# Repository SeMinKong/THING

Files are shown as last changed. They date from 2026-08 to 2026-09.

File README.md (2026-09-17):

<p align="center">
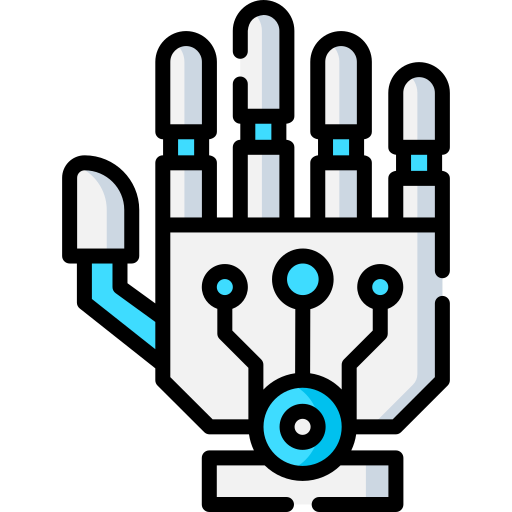
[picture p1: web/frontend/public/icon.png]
THING 로봇 손 로고
  
</p>

<h1 align="center">THING</h1>

<p align="center">
  <strong>손동작 인식부터 안전한 7축 구동과 실험 데이터 기록까지 연결한 텐던 로봇 핸드</strong>
</p>

THING은 사용자의 손동작을 실시간으로 인식해 7축 텐던 구동 로봇 손으로 재현하는
ROS 2 기반 Human-Mimetic Robot Hand입니다. MediaPipe가 검출한 21개 손 landmark를
네 손가락의 굽힘과 엄지의 굽힘·대립·벌림으로 구성된 7축 명령으로 변환합니다.

Jetson Orin Nano는 비전 인식과 동작 기록을, Raspberry Pi 5는 명령 중재·안전 검증과
DYNAMIXEL 제어를 담당합니다. React 관제 웹과 EC2 데이터 포털을 연결해 실시간 제어부터
실험 데이터 저장·조회까지 하나의 흐름으로 구현했습니다.

> **현재 구현 상태**
>
> 비전 인식, 명령 중재, 안전 검증, 7축 모터 구동, Web Bridge, 데이터 기록·업로드
> 경로를 통합했으며 실제 텐던 로봇 손으로 손동작 모방과 물체 파지 시연을 완료했습니다.

## 시연

### 최종 통합 시연

사용자의 손동작 인식과 7축 텐던 로봇 손의 실시간 모방 제어를 보여주는 최종 시연입니다.

https://github.com/user-attachments/assets/3f23d3e1-5532-4831-a1eb-fe4c024d04cb

> [원본 최종 시연 영상 열기](media/videos/모방시연.mp4)

### 동작 하이라이트

아래 미리보기는 모방·파지·독립 관절 동작 9개를 짧게 이어 보여줍니다.

<p align="center">
  실시간 손동작 모방, 여러 손동작 모방, 지연 개선 웨이브, 캔 파지, 유연 물체 파지, 손목보호대 파지, 엄지 3축, 손가락 웨이브, 카운트다운 시퀀스 하이라이트
</p>

<p align="center">
  <sub>각 동작의 전체 영상은 아래 목록에서 확인할 수 있습니다.</sub>
</p>

### 개별 시연 영상

<details>
<summary><strong>전체 원본 영상 펼쳐보기</strong></summary>

#### 통합·모방

- [최종 손동작 모방 시연](media/videos/모방시연.mp4)
- [7축 구동 시연](media/videos/최종시연.mp4)
- [여러 손동작 모방](media/videos/모방여러동작.mp4)
- [지연 개선 후 웨이브 모방](media/videos/모방웨이브지연개선.mp4)

#### 파지·시퀀스

- [캔 파지 모방](media/videos/모방캔파지.mp4)
- [유연한 물체 파지](media/videos/파지말랑이.mp4)
- [손목보호대 파지](media/videos/파지손목보호.mp4)
- [엄지 3축 동작](media/videos/엄지축.mp4)
- [손가락 웨이브](media/videos/파도타기.mp4)
- [카운트다운 시퀀스](media/videos/카운트다운.mp4)

</details>

원본 MP4 영상은 Git LFS로 관리합니다.

## 핵심 구현

| 영역 | 구현 내용 |
| --- | --- |
| 기구·전자 | 3D 프린팅 텐던 로봇 손, CAD·STL·URDF, 7축 DYNAMIXEL 배선과 안전 전원 자료 |
| 비전 | USB 카메라 프레임, MediaPipe Hands 기반 21개 landmark 검출, 정규화된 7축 `HandCommand` 생성 |
| 제어·안전 | MIMIC·MANUAL·TELEOP 명령 중재, Command Guard, GPIO E-Stop, 안전 상태 관리, XL330-M288-T 7축 구동 |
| 관제 UI | WebSocket·MJPEG 기반 실시간 상태 확인, 제어권 관리, 모방·수동 조작, 기록 판정 UI |
| 기록·데이터 | rosbag2 기록, metadata·Landmark JSON과 HandCommand·MotorStatus CSV exporter, SHA-256 검증, HTTPS uploader, EC2 세션 포털 |
| 운용 | ROS 2 장치별 launch, Jetson 비전·웹 실행 스크립트, Raspberry Pi 시연 자동화 스크립트 |

## 시스템 구성

```text
사용자 손
  → Camera / MediaPipe / 7축 목표 생성                (Jetson Orin Nano)
  → command_manager / command_guard / safety_manager (Raspberry Pi 5)
  → DYNAMIXEL XL330-M288-T × 7
  → 텐던 로봇 손

카메라·로봇 상태
  → Web Bridge (WebSocket + MJPEG)
  → React 관제·제어 웹                               (Laptop)

동작 데이터
  → rosbag2 → exporter → uploader                    (Jetson Orin Nano)
  → Django API / SQLite / 파일 저장                  (AWS EC2)
```

웹은 모터를 직접 제어하지 않습니다. 모든 일반 명령은 Raspberry Pi의 명령 중재와
안전 검증을 통과하며, 네트워크가 복구돼도 사용자의 명시적인 입력 전에는 자동으로
움직이지 않도록 구성했습니다.

## 직접 구현한 부분

- Codex의 Blender 스킬을 활용해 인체 손의 관절 구조를 모방한 모델을 설계하고, 3D 프린팅으로 제작했습니다.
- DYNAMIXEL 모터 7개의 제어값을 조정하고, 동기 구동과 키보드 기반 조작 기능을 구현했습니다.
- U2D2 기반 모터 통신 모듈을 구성하고, 제어 노드에서 전달한 데이터를 모터 명령으로 변환하는 ROS 브릿지를 구현했습니다.

## 트러블슈팅

- **모터 제어 범위 조정**: DYNAMIXEL SDK의 전류 제한, 토크 설정, 회전 범위, 제어 모드별 동작을 확인했습니다. 각 파라미터가 구동에 미치는 영향을 비교하며 로봇손의 기구 조건에 맞게 제어값을 조정했습니다.
- **텐던 구동과 복귀 구조**: 손가락을 굽히는 동작과 원위치로 복귀하는 동작을 함께 고려해야 했습니다. 관절의 힘 작용점을 계산하고 텐던 배치를 검토해, 장력을 이용하는 복귀 방식으로 구조를 변경했습니다.
- **ROS 통신 주기 개선**: 제어 명령의 전달 주기를 개선하기 위해 ROS 통신 설정을 조정하고 Cyclone DDS를 활용했습니다. 모터 구동과 데이터 전달을 함께 점검하며 실시간 제어를 위한 통신 환경을 구성했습니다.

## 회고

Physical AI를 위한 시뮬레이션 학습까지 진행하지는 못했지만, 로봇의 기구와 모터 제어를 연결하는 기초를 익혔습니다. 제작 과정에서 통신 오류와 하드웨어 한계를 경험하며 소프트웨어만으로 해결하기 어려운 조건들을 이해했습니다. 이를 바탕으로 기구·통신 구조를 개선하고, 이후 시뮬레이션 학습과 실제 제어를 연결할 프로젝트를 구상하고 있습니다.

## 구동부 구현과 설계 판단

저는 **Blender 모델링·3D 프린팅, U2D2 통신·7개 모터 동기 구동·키보드 제어, ROS 브릿지와 Cyclone DDS 통신 설정, 고정부·스풀·텐던 통합**을 담당했습니다. 손동작 인식, 명령 중재·guard·안전 상태, 관제 UI·기록 등은 팀원이 구현했습니다. 아래 표에는 제가 작성한 모터 점검 코드의 세부 처리를 정리했습니다.

| 확인한 문제 | 구현한 처리 | 확인 범위 |
| --- | --- | --- |
| 토크를 켤 때 이전 목표로 움직일 수 있음 | 이동 함수에서 현재 위치를 Goal Position에 먼저 기록 → Torque ON → 새 목표 적용 | 모터 점검 코드의 실행 순서 |
| 다회전 위치에서 원위치 복귀 경로가 길어짐 | 현재 위치에 가장 가까운 `2048 + 4096 × k` 선택 | 중앙각 복귀이며 손가락 끝점 보정과 구분 |
| 같은 엔코더 명령도 기구 상태에 따라 굽힘량이 달라짐 | 모터별 점검과 아크릴 고정부·스풀·텐던 조립, 권취·배선 경로 기록 | 최대 가동 범위 간섭·재조립 반복성은 추가 검증 필요 |

관절각·필터·모터 보정식, 토크 인가 순서와 실제 검증 범위는
[구동·기구 통합 기술 노트](docs/engineering-notes.md)에 정리했습니다.

## 기술 스택

| 구분 | 기술 |
| --- | --- |
| Robot·Edge | ROS 2 Humble, Jetson Orin Nano, Raspberry Pi 5 |
| Vision | MediaPipe Hands, OpenCV |
| Control | Python, C++, DYNAMIXEL XL330-M288-T, U2D2 |
| Web | React, Vite, WebSocket, MJPEG |
| Data | rosbag2, Django, SQLite, JSON·CSV, AWS EC2 |
| Fabrication | Blender, 3D Printing, Tendon-driven Mechanism |

## 빠르게 확인하기

### 저장소 받기

Git LFS가 필요합니다.

```bash
git lfs install
git clone https://github.com/SeMinKong/THING.git
cd THING
git lfs pull
```

### 로봇 없이 관제 UI 실행

```bash
cd web/frontend
npm ci
npm run mock
```

다른 터미널에서 다음 명령을 실행합니다.

```bash
cd web/frontend
npm run dev
```

### ROS 2 패키지 빌드

Ubuntu 22.04와 ROS 2 Humble 환경을 기준으로 합니다.

```bash
source /opt/ros/humble/setup.bash
cd thing_ws
rosdep install --from-paths src --ignore-src -r -y
colcon build --symlink-install
source install/setup.bash
colcon test
colcon test-result --verbose
```

실물 장비를 구동하기 전에는 장치별 설정과 안전 문서를 먼저 확인하세요.

## 저장소 구성

| 경로 | 내용 |
| --- | --- |
| [`mechanical/`](mechanical/) | CAD, STL, 도면과 조립 자료 |
| [`electronics/`](electronics/) | BOM, 회로, 배선과 안전 전원 자료 |
| [`thing_ws/`](thing_ws/) | ROS 2 인터페이스·비전·제어·하드웨어·로거·Web Bridge·bringup |
| [`web/frontend/`](web/frontend/) | 내부망 React 관제·제어 UI |
| [`scripts/`](scripts/) | Jetson 비전·Web Bridge 실행 스크립트 |
| [`exec/`](exec/) | Raspberry Pi 시연 실행·종료 스크립트 |
| [`EC2/thing_database_web/`](EC2/thing_database_web/) | 실험 데이터 포털 프런트엔드·백엔드 |
| [`tests/`](tests/) | 자동화 테스트와 실물 시험 절차 |
| [`docs/`](docs/) | 요구사항, 아키텍처, 인터페이스, 환경 설정과 개발 기록 |
| [`media/`](media/) | 프로젝트 이미지와 시연 영상 |

## 주요 문서

- [구동·기구 통합 기술 노트](docs/engineering-notes.md)
- [시스템 아키텍처](docs/architecture.md)
- [ROS 2·Web·EC2 인터페이스](docs/interfaces.md)
- [요구사항 명세서 V7.1](docs/requirements/요구사항%20명세서%20V7.1.md)
- [포팅 매뉴얼](exec/포팅_매뉴얼.md)
- [Safety Manager](docs/safety_manager.md)
- [Ubuntu 개발 환경](docs/setup/ubuntu.md)
- [DYNAMIXEL 설정](docs/setup/dynamixel.md)
- [내부 관제 웹](web/README.md)
- [Web Bridge](thing_ws/src/thing_web_bridge/README.md)
- [Logger·Landmark JSON 계약](thing_ws/src/thing_logger/README.md)
- [기구 자료](mechanical/README.md)
- [전자·배선 자료](electronics/README.md)
- [시험 절차](tests/README.md)
- [EC2 데이터 포털](EC2/README.md)

## Contributors

<p align="center"><strong>SSAFY 광주 1반 C103</strong></p>

<table align="center">
  <tr>
    <td align="center" width="160">
      <a href="https://github.com/binedwin">
        이정빈 GitHub 프로필<br>
        <strong>이정빈</strong>
      </a><br>
      <sub>팀장</sub>
    </td>
    <td align="center" width="160">
      <a href="https://github.com/s0415j">
        신수진 GitHub 프로필<br>
        <strong>신수진</strong>
      </a><br>
      <sub>팀원</sub>
    </td>
    <td align="center" width="160">
      <a href="https://github.com/akdlxm39">
        백지웅 GitHub 프로필<br>
        <strong>백지웅</strong>
      </a><br>
      <sub>팀원</sub>
    </td>
  </tr>
  <tr>
    <td align="center" width="160">
      <a href="https://github.com/yjmini">
        윤정민 GitHub 프로필<br>
        <strong>윤정민</strong>
      </a><br>
      <sub>팀원</sub>
    </td>
    <td align="center" width="160">
      <a href="https://github.com/lab0-hibears">
        김기현 GitHub 프로필<br>
        <strong>김기현</strong>
      </a><br>
      <sub>팀원</sub>
    </td>
    <td align="center" width="160">
      <a href="https://github.com/SeMinKong">
        공세민 GitHub 프로필<br>
        <strong>공세민</strong>
      </a><br>
      <sub>팀원</sub>
    </td>
  </tr>
</table>

## 안전

실제 모터에 토크를 인가하기 전에 모터 ID, 이동 범위, 전류 제한, 텐던 장력과
비상 정지·전원 차단 수단을 확인해야 합니다.

- [DYNAMIXEL 도구와 기본 점검](tools/dynamixel/README.md)
- [모터 제어 안전 지침](docs/motor-control/dynamixel/safety.md)
- [Raspberry Pi 현장 제어 안내](tools/dynamixel/rpi/README.md)

## 라이선스

이 프로젝트는 [Apache License 2.0](LICENSE)으로 배포됩니다.

## 원본 프로젝트 README

이 저장소는 SSAFY 팀 GitLab 프로젝트 `main`의 최종 스냅샷을 포트폴리오 형태로
정리한 버전입니다. 팀 개발 저장소에서 사용한 기술·협업 중심 README는
[README_LEGACY.md](README_LEGACY.md)에 보존했습니다.

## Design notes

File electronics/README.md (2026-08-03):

# Electronics

이 디렉터리는 `schematics/`의 회로도, `wiring/`의 실제 배선 자료와 `bom/`의 부품 목록을 관리합니다.

서보 전원, 마이크로컨트롤러, 배선, 센서와 안전장치를 관리합니다.

현재 MVP는 Raspberry Pi와 U2D2가 XL-330-288T 7개를 직접 제어하며 별도
마이크로컨트롤러를 사용하지 않습니다. 모터 1개는 예비입니다.

- `schematics/`: 회로도
- `wiring/`: 실제 배선도와 사진
- `bom/`: 부품 목록과 구매 상태

배선 문서에는 motor ID, U2D2 포트, 전원 분배, 퓨즈와 비상정지의 물리 전원
차단 경로를 반드시 표시합니다.

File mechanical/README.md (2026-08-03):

# Mechanical

이 디렉터리는 `cad/`의 설계 원본, `stl/`의 출력 파일과 `drawings/`의 치수·조립 도면을 관리합니다.

손가락 링크, 관절, 엄지 대립축, tendon 경로, spool 및 서보 마운트를 관리합니다.

- `cad/`: 수정 가능한 CAD 원본
- `stl/`: 3D 프린팅용 출력 파일
- `drawings/`: 치수 도면과 조립도

CAD 변경 MR에는 출력 방향, 소재, 조립 방법과 동작 시험 결과를 함께 기록합니다.

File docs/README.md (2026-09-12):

# Docs

이 디렉터리는 프로젝트 계획, 시스템 아키텍처, 분야 간 인터페이스와 일간·주간 진행 기록을 관리합니다.

- `requirements/`: 요구사항 명세서 버전 이력 관리 (`V6.3`이 현재 최종 기준)
- `setup/`: Ubuntu, Jetson, Raspberry Pi, 네트워크와 DYNAMIXEL 설정
- `daily-reports/`: 팀원별 일일 진행 상황과 장애 요소 기록
- `weekly-reports/`: 주간 목표, 결과와 다음 주 우선순위 기록

- [구동·기구 통합 기술 노트](engineering-notes.md): 개인 기여, 관절각·필터·보정식, 운용 주기와 검증 범위

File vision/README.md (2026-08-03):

# Vision experiments

이 디렉터리는 사용자 캘리브레이션 자료와 ROS 2에 넣기 전의 제한된 비전 실험을
관리합니다. 실제 실행 노드와 공용 알고리즘은
`thing_ws/src/thing_vision`에서 구현합니다.

- `calibration/`: 사용자별 편 손·주먹 기준과 샘플
- `experiments/`: 필요할 때 생성하는 일회성 MediaPipe·기하 계산 실험
- `requirements.txt`: ROS 비전 노드와 실험에서 공통으로 사용하는 Python 의존성

프로덕션 코드가 이 디렉터리와 `thing_vision`에 중복되지 않도록 합니다.

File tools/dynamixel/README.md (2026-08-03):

# DYNAMIXEL XL330 PC 제어 도구

XL330-M288-T 7축의 연결 상태를 확인하고, 안전한 보정·동작 계획을 수행하는 독립 실행 도구다. ROS 2 `thing_hardware` 통합 전의 PC·Raspberry Pi 하드웨어 점검에 사용하며, 운영 제어 경로를 대체하지 않는다.

## 설치

```bash
python3 -m venv dxl-env
source dxl-env/bin/activate
python -m pip install -r tools/dynamixel/requirements.txt
cp tools/dynamixel/hand_motion_config.example.json \
  tools/dynamixel/hand_motion_config.json
```

실제 장치별 포트, ID, 관절 역할, 개폐 위치값은 로컬 설정 파일에만 기록한다. 이 파일과 CSV 텔레메트리는 Git에서 제외된다.

## 기본 점검

```bash
python tools/dynamixel/scan_7_motors.py
python tools/dynamixel/hand_motion_7_motors.py plan
python tools/dynamixel/hand_motion_7_motors.py show
python -m unittest tests/dynamixel/test_hand_motion_offline.py -v
```

실제 토크 인가 전에는 모든 축의 역할과 이동 범위를 확인하고, 비상 정지와 전원 차단 수단을 준비한다.

## 관련 문서

- [실제 손 동작 코드 사용 순서](../../docs/motor-control/dynamixel/hand-motion.md)
- [배포 절차](../../docs/motor-control/dynamixel/deployment.md)
- [안전 지침](../../docs/motor-control/dynamixel/safety.md)
- [이식성 및 장치 설정](../../docs/motor-control/dynamixel/portability.md)
- [프로젝트 상태](../../docs/motor-control/dynamixel/project-status.md)

## Raspberry Pi 현장 제어 스크립트

`rpi/`에는 Raspberry Pi의 `~/thing_pjt/motor`에서 실제 7축 XL330·3개 U2D2 연결에 사용한
점검·제어 스크립트를 보관한다. 통합 손 동작 제어기와는 별도의 현장 점검 도구이며, 다음 작업을
포함한다.

- 7개 모터 통신·상태 조회와 단일 모터 제어
- 개별/전체 Torque OFF가 가능한 키보드 제어
- 모든 축의 2048 기준 원위치 복귀 및 출력 제한값 설정

`rpi/motor_config.json`에는 해당 장비의 `/dev/serial/by-id/` U2D2 경로가 들어 있다. 다른
제어기에서 사용하기 전에는 경로와 모터 ID를 확인하고 수정해야 한다. 상세 사용법은
[`rpi/README.md`](rpi/README.md)를 따른다.

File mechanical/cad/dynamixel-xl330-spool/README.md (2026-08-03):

# XL330 / HNX330-N101용 Ø12 저상형 2피스 스풀

이 설계는 손가락 굽힘용 2 mm 텐던을 부드럽게 제어하기 위한 **Ø12 mm 감김 드럼**과, HNX330-N101 호른에 고정되는 **분리형 베이스**로 구성됩니다.

호른 체결 나사가 작은 드럼의 감김면을 관통하지 않도록 베이스와 드럼을 분리했습니다. 장식용 줄 형상과 나선 홈은 없습니다.

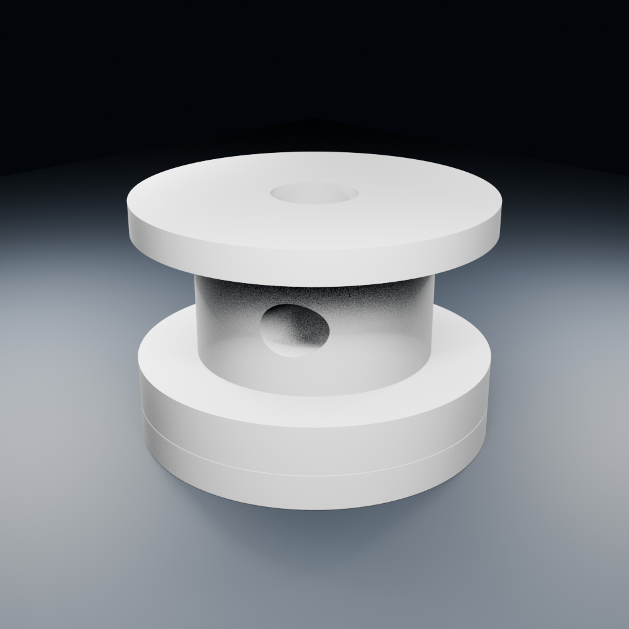
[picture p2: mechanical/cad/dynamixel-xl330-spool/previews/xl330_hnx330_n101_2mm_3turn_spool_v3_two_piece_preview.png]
조립 미리보기


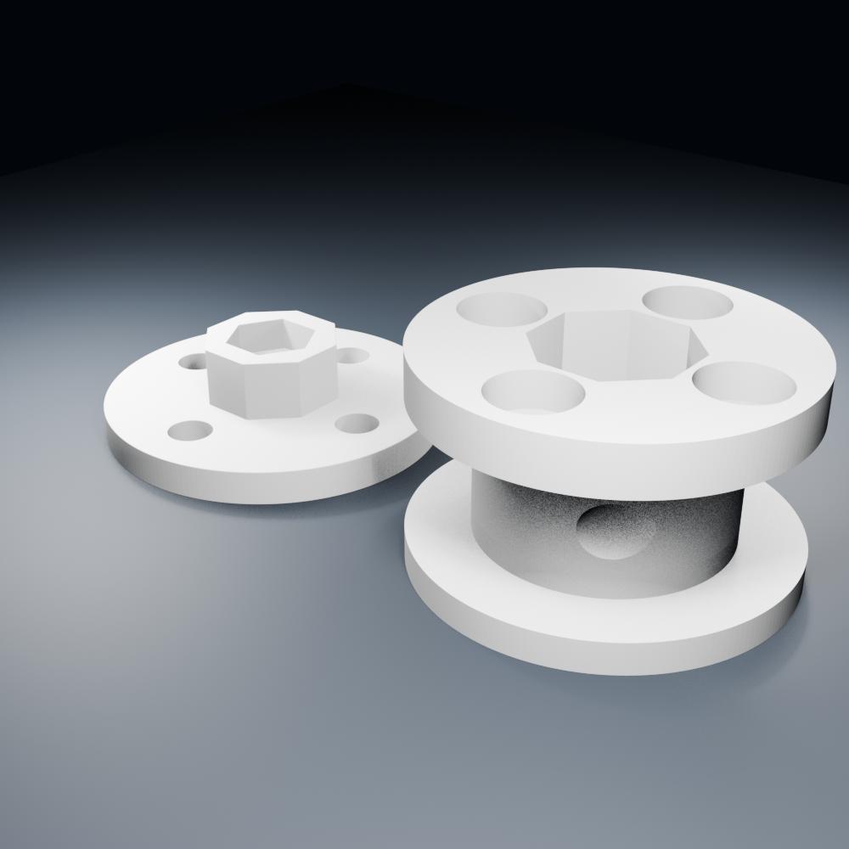
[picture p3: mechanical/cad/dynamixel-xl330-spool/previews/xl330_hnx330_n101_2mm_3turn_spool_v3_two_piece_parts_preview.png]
부품 및 출력 방향 미리보기


## 구성 파일

- `print/..._mount_base.stl`: 호른에 고정하는 베이스
- `print/..._drum.stl`: 2 mm 줄이 감기는 교체형 드럼
- `print/..._7set_bambu_plate.3mf`: 베이스 7개와 드럼 7개가 배치된 Bambu Studio 생산 플레이트
- `source/..._assembly.blend`: 두 부품이 결합된 Blender 원본
- `scripts/create_xl330_two_piece_spool.py`: 파라메트릭 Blender 생성 스크립트
- `scripts/validate_xl330_two_piece_spool.py`: 커밋된 STL 검증 스크립트

모델을 다시 생성하면 결과는 Git에서 제외된 `generated/`에 저장됩니다.

```bash
blender --background --python scripts/create_xl330_two_piece_spool.py
blender --background --python scripts/validate_xl330_two_piece_spool.py
```

## 주요 치수

### 드럼

| 항목 | 치수 |
|---|---:|
| 감김 코어 | Ø12.00 mm |
| 플랜지 외경 | Ø18.00 mm |
| 감김 유효 폭 | 6.50 mm |
| 줄 용량 | Ø2.00 mm 줄 1가닥 × 나란히 3회 |
| 하부 플랜지 | 2.40 mm |
| 상부 플랜지 | 1.60 mm |
| 드럼 전체 높이 | 10.50 mm |
| 팔각 허브 보어 | AF 7.25 mm × 깊이 3.60 mm |
| 중앙 체결홀 | Ø2.30 mm |
| 중앙 나사머리 자리 | Ø4.30 mm × 깊이 1.50 mm |
| 줄 고정용 가로 구멍 | Ø2.60 mm |

### 호른 베이스

| 항목 | 치수 |
|---|---:|
| 베이스 원판 | Ø18.00 × 1.80 mm |
| 호른 체결홀 | 4 × Ø2.30 mm |
| 체결홀 피치원 | PCD Ø12.00 mm |
| 팔각 토크 허브 | AF 6.80 × 높이 3.20 mm |
| 드럼과 팔각 끼움 여유 | 직경 방향 0.45 mm |
| 중앙 M2 너트 포켓 | AF 4.25 × 깊이 1.80 mm |
| 호른 중앙 나사 여유부 | Ø6.00 × 깊이 0.50 mm |
| 결합 상태 전체 높이 | 호른 면에서 12.30 mm |

모터 위치 범위 `100~3995 raw`를 전부 사용하면, 2 mm 줄 중심 기준 약 **41.824 mm**를 당깁니다. 이 값은 기하학적 최대 환산값이며 실제 손에서는 사용하지 않습니다. 텐던 연결 후 축별 안전 끝점을 작은 조그로 따로 보정해야 합니다.

## 필요한 체결 부품

- 호른 체결: **PHS M2×4 4개**
  - HNX330-N101에 포함된 나사를 사용할 수 있습니다.
- 드럼 체결: **M2×8 나사 1개**
  - 냄비머리 또는 버튼머리
  - 실제 나사머리 외경은 4.1 mm 이하 권장
- 드럼 체결용 **표준 M2 육각너트 1개**
  - 공칭 AF 4.0 mm, 두께 약 1.6 mm

## 권장 출력 설정

- 재료: PETG 또는 Nylon 권장
- 노즐: 0.4 mm
- 레이어: 0.16~0.20 mm
- 벽: 5겹 이상
- 상·하부: 6겹 이상
- 인필: 100% 권장
- 배율: 100%, 단위 mm

제공된 3MF에는 베이스와 드럼이 각각 7개 배치되어 있습니다. Bambu Studio 2.7.1.62에서 작성했지만, 출력 전에 사용 중인 프린터·노즐·필라멘트 프로파일과 서포트 설정을 반드시 다시 확인합니다.

출력 방향:

- 베이스: 평평한 호른 접촉면을 베드에 놓고 팔각 허브가 위를 향하게 출력
- 드럼: 중앙 M2 나사머리 자리가 있는 면을 베드에 놓고, 팔각 보어와 나사머리 포켓이 위를 향하게 출력

드럼의 마지막 플랜지 밑면이 처지는 프린터에서는 감김 공간에만 `build plate only` 서포트를 적용합니다.

출력 후 다음 부분을 손으로 정리합니다.

- M2 체결홀: Ø2.3 드릴
- 호른 나사머리 포켓: 실제 나사머리가 완전히 들어가도록 Ø4.1 드릴 또는 리머
- 줄 고정홀: Ø2.6 드릴
- 팔각 끼움이 너무 빡빡하면 베이스 허브의 평평한 면만 조금씩 사포질

## 조립 순서

1. 모터 전원을 끄고 토크가 해제됐는지 확인합니다.
2. 베이스의 구멍 4개를 HNX330-N101의 M2 나사홀에 맞춥니다.
3. PHS M2×4 나사 4개를 모두 가볍게 건 뒤 대각선 순서로 조금씩 조입니다.
4. 표준 M2 육각너트를 베이스 팔각 허브 중앙의 육각 포켓에 넣습니다.
5. 드럼 밑면의 나사머리 포켓 4개를 베이스 나사머리에 맞추면서 팔각 허브에 끼웁니다.
6. 드럼 위에서 M2×8 나사를 넣어 중앙 너트에 가볍게 조입니다.
7. 2 mm 줄을 드럼의 Ø2.6 가로 구멍으로 통과시킨 뒤 나란히 최대 3회 감습니다.

중앙 M2 나사는 드럼이 빠지지 않게 누르는 역할이고, 회전 토크는 팔각 허브가 전달합니다. 플라스틱을 압착할 정도로 중앙 나사를 세게 조이지 마십시오.

## 검증 결과

### 베이스 STL

- 외형: 18.0000 × 18.0000 × 5.0000 mm
- 연결된 메쉬: 1개
- 비매니폴드 에지: 0개
- 느슨한 정점: 0개

### 드럼 STL

- 외형: 18.0000 × 18.0000 × 10.5000 mm
- 연결된 메쉬: 1개
- 비매니폴드 에지: 0개
- 느슨한 정점: 0개

### 조립 여유

- 팔각 AF 여유: 0.450 mm
- M2 너트 AF 여유: 0.250 mm
- 호른 나사머리 포켓 위 잔여 두께: 0.600 mm
- 줄 고정홀과 중앙 M2 홀 사이 최소 여유: 0.950 mm

## 적용 대상

이 모델은 ROBOTIS 공식 도면의 `외경 Ø16`, `4-M2×0.4 TAP THRU`, `PCD Ø12` 체결 패턴을 가진 **HNX330-N101** 기준입니다.

- [ROBOTIS HNX330-N101 제품 정보](https://www.robotis.us/hnx330-n101-set/)
- [ROBOTIS 공식 도면 다운로드 센터](https://en.robotis.com/service/downloadpage.php?ca_id=7020)

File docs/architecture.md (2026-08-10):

# 시스템 아키텍처

## 장치별 책임

| 장치 | 책임 |
| --- | --- |
| Jetson Orin Nano | RGB 카메라, MediaPipe, 7논리축 목표, overlay/MJPEG, Web Bridge, Logger·exporter·uploader |
| Raspberry Pi 5 | 제어권 중재, 명령 검증, 안전, DYNAMIXEL |
| Laptop | 내부망 관제·제어 웹, TELEOP와 개발 |
| AWS EC2 | 공개 데이터 포털, SQLite와 세 파일 영속 저장 |

## 제어 데이터 흐름

```text
사용자 손
  → camera_node
  → mediapipe_node
  → HandLandmarks
  → hand_target_node
  → /thing/command/mimic
                         ┐
웹 Gesture/Sequence ─────┼→ command_manager → /thing/command/selected
로컬 TELEOP ─────────────┘
  → command_guard
  → /thing/command
  → dynamixel_node
  → XL-330-288T × 7
  → MotorStatus / diagnostics
```

웹은 모터에 직접 명령하지 않습니다. 모든 일반 명령은 `command_manager`와
`command_guard`를 통과해야 합니다.

## 관제와 기록 흐름

```text
camera overlay → MJPEG ───────────────────────┐
ControlState / SafetyState / RecordingState ──┼→ thing_web_bridge
HandCommand / MotorStatus ────────────────────┘       │
                                                      ├→ WebSocket → Laptop 내부 제어 웹
                                                      └→ MJPEG ────→ Laptop 내부 제어 웹

MIMIC recording request
  → thing_logger
  → rosbag2(HandLandmarks, HandCommand, MotorStatus, state topics)
  → 사용자 SUCCESS/FAILURE 판정
  → Logger 측 exporter
  → metadata JSON + HandCommand CSV + MotorStatus CSV
  → 격리 uploader 데몬(thing_logger.uploader, 별도 프로세스)
  → Bearer Token HTTPS
  → EC2 Django STAGING 검증
  → EC2 SQLite READY + EC2_DATA_DIR
  → 공개 GET 조회·세 파일 다운로드
```

카메라와 Vision은 녹화 여부와 무관하게 계속 동작합니다. 카메라 영상은 MJPEG
관제에만 사용하고 파일 또는 rosbag2에 저장하지 않습니다.

로봇의 로컬 시계열 원본은 rosbag2입니다. 별도 애플리케이션 SQLite,
`session_state.json`과 영구 upload spool은 만들지 않습니다. 업로드 실패 세션은
보존된 rosbag2와 SUCCESS/FAILURE를 입력받는 수동 재업로드 절차로 처리합니다.

## 제어 모드와 안전

- `DISABLED`: 일반 명령 차단
- `MIMIC`: MediaPipe 명령 사용
- `MANUAL`: 웹 Gesture·Sequence 사용
- `TELEOP`: 로컬 키보드 개별축 제어

안전 상태는 `INIT → READY → RUN → HOLD → SAFE/FAULT`로 관리하며 비상정지는
별도 `ESTOP` 상태입니다. Raspberry Pi의 제한과 비상정지는 웹·Jetson 장애와
독립적으로 동작해야 합니다.

`SAFE`, `FAULT`, `ESTOP` 복구는 `/thing/reset_safety`의 INIT 재검사를 거쳐
READY까지만 전환합니다. 이전 mode·owner·명령·queue·녹화는 자동 복원하지
않습니다.

## 네트워크 원칙

- 프로젝트 내부망에서만 제어합니다.
- 장치들은 같은 ROS Domain ID와 합의된 DDS 설정을 사용합니다.
- 명령 timestamp는 장치 간 시간 동기화를 전제로 합니다.
- 네트워크가 복구돼도 명시적인 재개 입력 전에는 자동으로 움직이지 않습니다.
- EC2에는 ROS 2 DDS와 로봇 제어 API를 노출하지 않습니다.
- EC2 포털은 HTTPS 공개 GET으로 READY 데이터만 조회하고, 업로드는 장치별
  Bearer Token을 사용하는 Jetson uploader만 수행합니다.

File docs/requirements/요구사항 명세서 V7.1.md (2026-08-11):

# 요구사항 명세서 V7.1(이제 수정은 여기서!!!!!)

업무 영역: 기획
업무 항목 현황: 대기
개별 진행률: 0%
진행률: 0%
최종 편집 일시: 2026년 8월 5일 오후 5:40

## 변경 이력

| 버전 | 변경 내용 |
| --- | --- |
| V5 | ROS 2 인터페이스, 내부망 관제·제어 웹 및 데이터 기록 명세 |
| V5.2 | V5의 누락 항목 보완 및 7논리축·7모터 구조 통일 |
| V6 | EC2 기반 외부 데이터 포털 추가, develop ROS 2 인터페이스 동결, 로봇의 별도 애플리케이션 DB 제거와 rosbag2 기반 EC2 직접 업로드, 안전 정책·2주 우선순위 및 Docker 배치 정합성 보정. Logger exporter·격리 uploader 분리, 수동 재업로드 CLI, content_digest 멱등성, Laptop 내부 제어 웹·두 웹 디렉터리와 WebSocket·EC2 GET JSON 계약 확정 |

## 1. 프로젝트 개요

### 1.1 프로젝트 배경 및 목적

본 프로젝트는 카메라로 사용자의 오른손 자세를 인식하고, 텐던 방식의 3D 프린팅 로봇 손이 해당 자세를 실시간으로 따라 움직이도록 구현하는 것을 목적으로 한다. 각 손가락의 여러 관절을 하나의 모터로 함께 구동하는 언더액추에이티드 구조를 적용해 가격·무게·제작 난도를 낮추고, 제한된 기간 안에 반복 가능한 파지 성능을 검증한다.

현재 MVP의 핵심 시연 범위는 다음과 같다.

- 편 손·주먹 및 엄지 굽힘·대립·벌림을 포함한 7논리축 실시간 모방
- 원통형 물체 파지와 엄지–검지 집기
    - ROS 2 기반 내부망 명령 전달과 Raspberry Pi의 독립 안전 제어
- MediaPipe landmark, HandCommand, MotorStatus 및 실험 결과의 로컬 rosbag2 기록
- 내부망 관제·제어 웹의 MIMIC·MANUAL 운용
- EC2 데이터 포털의 완료 세션 조회와 metadata JSON·HandCommand CSV·MotorStatus CSV, LandMark JSON 다운로드

EC2 데이터 포털은 저장된 데이터의 공개 읽기 전용 서비스이며 로봇 제어 경로를 제공하지 않는다. 장기적인 학습 데이터·모델 사업화는 현재 MVP 범위에 포함하지 않는다.

프로젝트 전체 계획은 3주이며, 이 문서를 동결하는 시점의 잔여 개발 기간은 2주다. Must 기능의 통합 시연을 우선하고 Should·Could 기능은 Must 검수에 영향을 주지 않는 범위에서만 진행한다.

---

### 1.2 MVP

1. **로봇 손 구동**
    - 제작 범위
        - 3D 모델링
        - 관절 연결
        - 텐던 연결
        - 모터 연결
    - 검증 동작
        - 손 펴기와 쥐기
        - 원통형 물체 파지
        - 엄지–검지 집기
        - 가벼운 물체 2종을 각각 10회 시험하여 7회 이상 파지
2. **실제 손동작 모방**
    - MediaPipe 기반 손 landmark 검출
    - 손가락 굽힘과 엄지 대립 및 벌림 정도 계산
    - 모터에 전달
    - 7논리축을 7개 물리 모터에 1:1로 연결한다
    - 손동작 모방을 `camera_node → mediapipe_node → hand_target_node`로 구체화
3. **ROS 2 패키지**
    - ROS 2 토픽·노드·서비스·액션 인터페이스 정의 및 구현
    - ROS 2를 통한 무선 명령 전달
    - ROS 2를 이용한 모터 동작
4. **완성형 웹 사용자 인터페이스**
    - 모방 모드에서 실시간 카메라 영상과 손 인식 결과 모니터링
    - 조작 모드에서 웹 버튼으로 로봇 손 제어
    - 모방 모드와 조작 모드는 별도 화면 또는 탭으로 구성
5. **EC2 기반 로봇 데이터 포털**
    - 기존 내부망 관제·제어 웹과 별도의 웹사이트로 구성한다.
    - 완료된 실험 세션 목록을 조회할 수 있다.
    - 세션별 HandCommand와 MotorStatus 데이터를 확인할 수 있다.
    - 세션 메타데이터 JSON과 HandCommand·MotorStatus CSV·LandMark JSON을 모두 다운로드할 수 있다.
    - 원본 rosbag2 업로드·다운로드는 2주 MVP에서 제외하고 Post-MVP Could로 분류한다.
    - EC2 웹에서는 로봇 제어, 녹화 시작·종료 및 모드 변경 기능을 제공하지 않는다.

#### MVP 제외 범위 - 향후 확장 기능

- 관절 각 선형 회귀 AI 모델 - Could
- VLA 기반 자율 조작
- Imitation Learning 모델 학습
- Isaac Sim 및 Isaac Lab 연동
- 손가락 관절별 독립 다축 제어
- 모든 관절의 실제 각도 측정
- 손가락 전체 촉각 센서
- 물체 종류 자동 인식
- 물체 위치 자동 탐색
- 클라우드 또는 외부 인터넷을 통한 로봇 원격 제어
- 산업용 수준의 방수·방진·내구성 확보
- 축–모터 결합·공유 구동은 MVP에서 사용하지 않는다

EC2 기반 데이터 조회 및 다운로드 기능은 MVP에 포함한다. 단, 외부 인터넷에서 로봇으로 명령을 전달하는 기능은 MVP 및 EC2 배포 범위에서 제외한다.

향후 학습 데이터 활용을 위해 MediaPipe landmark, 목표 명령, 모터 엔코더값 및 파지 성공 여부는 MVP에서도 저장한다.

---

### 1.3 제품 및 시스템 기능 요약

시스템은 손동작 인식, 명령 중재·검증, 모터·안전 제어, 실험 기록·업로드의 네 영역으로 구성한다. 상세 배치는 4장, ROS 2 계약은 6.3절, EC2 계약은 6.5절을 단일 기준으로 사용한다.

1. **내부망 관제·제어 웹**
    - 프로젝트 내부 네트워크에서 MIMIC·MANUAL 모드, MJPEG 영상, 손 검출, 7논리축 목표, 모터·안전·기록 상태를 제공한다.
    - 제어 요청은 Web Bridge와 검증된 ROS 2 인터페이스를 거치며 모터에 직접 접근하지 않는다.
    - 기록 시작·종료와 성공·실패 판정을 요청한다.
2. **EC2 데이터 포털**
    - 외부 인터넷에서 완료·판정된 단일 로봇 세션을 로그인 없이 조회한다.
    - metadata JSON, HandCommand CSV, MotorStatus CSV, LandMark JSON 정확히 네 파일을 표시·다운로드한다.
    - ControlState·SafetyState 변경 이력, 영상과 rosbag2는 MVP 공개 대상에서 제외한다.
    - 로봇 제어, 모드 변경, 기록 제어, Safety Reset 및 ROS 2 DDS 참여를 금지한다.

로봇에는 별도의 애플리케이션 SQLite, `session_state.json` 및 영구 upload spool을 두지 않는다. rosbag2가 로컬 원본이며, 정상 종료와 판정 완료 직후 `thing-logger`의 exporter가 정확히 네 파일을 임시 디렉터리에 생성·검증한다. 격리된 uploader는 rosbag2를 읽지 않고 완료된 네 파일만 받아 Bearer Token HTTPS로 EC2 Django 업로드 API에 즉시 전송한다. EC2 Django가 검증한 세션 정보는 EC2 SQLite에, 다운로드 파일은 `EC2_DATA_DIR`에 저장하며 이 둘이 공개 READY 데이터의 최종 기준이다. Laptop에서 실행하는 내부망 관제·제어 웹은 Web Bridge의 WebSocket과 Jetson MJPEG로 ROS 2 실시간 데이터를 받고, EC2 포털은 Django의 공개 GET API로 저장된 데이터만 조회한다.

MJPEG가 `/thing/image_raw`와 `/thing/landmarks`를 구독해 생성

#### 내부망 웹 기반 운용 흐름

- 카메라와 Vision Node는 기록 여부와 관계없이 계속 동작하며 원본 영상은 저장하지 않는다.
- MIMIC은 검출된 손으로 7논리축 명령을 생성하고 MANUAL은 사전 정의 자세를 실행한다.
- Raspberry Pi는 활성 mode·owner와 안전 상태에 맞는 입력 하나만 선택하고 유효성·범위·속도를 검증한다.
- 기록은 MIMIC에서만 허용하며 기록 중 모드 변경을 거부한다.

#### ROS 2 통합 실행 및 수동 시험

- 운영자는 장치별 실행 절차로 Laptop 내부 제어 웹, Jetson과 Raspberry Pi 스택을 시작한다.
- 필요 시 `teleop_keyboard`로 각 축을 시험한다.
- 편 손·주먹·파지·집기는 Must이며 가위바위보·카운트다운 Sequence는 Could다.

---

### 1.4 사용자 및 이해관계자

| 구분 | 역할 및 요구사항 |
| --- | --- |
| 조작 사용자 | 카메라 앞에서 손동작을 수행하거나 내부망 관제·제어 웹에서 명령을 선택해 로봇 손을 제어한다. |
| 기구 개발자 | 손가락, 텐던, 스풀, 스프링 및 모터 고정 구조를 설계하고 조정한다. |
| 소프트웨어 개발자 | MediaPipe, ROS 2, 모터 제어 및 데이터 저장 기능을 구현한다. |
| 웹 개발자 | 프론트엔드와 백엔드를 구현하고 사용자 화면을 설계한다. |
| 프로젝트 관리자 | 일정, 요구사항, 우선순위, 위험 요소 및 스프린트를 관리한다. |
| 평가자 및 관람자 | 손동작 모방, 물체 파지 동작을 확인한다. |
| 데이터 조회 사용자 | EC2 데이터 포털에 접속하여 세션별 로봇 데이터를 확인하고 다운로드한다. 로봇 제어 권한은 가지지 않는다. |
| 시스템 운영자 | EC2 서버, 데이터 업로드 상태, 저장 공간, 인증 정보 및 배포 상태를 관리한다. |

---

### 1.5 개발 환경

#### 1.5.1 하드웨어 환경

**현재 보유 장비**

- 3D 프린팅 로봇 손, 지름 2mm 철심과 텐던 소재
- U2D2 3개와 U2D2 Power Hub Board 3개
- DYNAMIXEL XL330-M288-T 8개: 활성 구동 7개, 예비 1개

**개발·통합 장비**

- Laptop, RGB 카메라, Jetson Orin Nano, Raspberry Pi 5
- 7개 모터의 순간 전류를 감당하는 별도 전원 공급 장치
- 스프링, 나일론선 및 물리적 E-Stop 주접점·NC 보조접점 회로

#### 1.5.2 소프트웨어 환경

- Jetson: JetPack 6.2·Ubuntu 22.04, Docker Engine. 비전·MJPEG·Web Bridge 이미지를 버전 관리된 `docker run` 스크립트로 실행하며 Docker Compose를 사용하지 않는다.
- Raspberry Pi: Ubuntu 24.04·Docker Engine. `docker compose up -d`를 유일한 표준 시작 방식으로 사용한다.
- Laptop: 내부망 제어 웹의 `web/*~~internal-control/~~*frontend` Vite+React를 native Node.js 환경에서 실행한다. Docker를 사용하지 않으며 브라우저는 Jetson Web Bridge WebSocket과 MJPEG에 내부망으로만 연결한다.
- EC2: Docker와 Compose를 사용하지 않는다. `EC2/frontend`의 React 정적 빌드를 Nginx가 제공하고 `EC2/backend`의 Django REST API·Gunicorn을 Python 가상환경과 systemd 서비스로 실행한다.
- 공통: ROS 2 Humble, C++·Python·JavaScript, OpenCV, MediaPipe, DYNAMIXEL SDK, rosbag2
- 내부망 웹: Laptop Vite+React, Jetson*~~(Django 삭제)*~~ ·Web Bridge WebSocket·MJPEG
- EC2 포털: Vite+React, Django REST API, Nginx, Gunicorn, HTTPS
- 로봇 로컬 저장(Jetson): `ROBOT_DATA_DIR=/var/lib/thing-robot-data` 아래 rosbag2 원본과 업로드 시점에만 생성하는 임시 네 파일. 별도 애플리케이션 SQLite·`session_state.json`·영구 spool은 사용하지 않음
- EC2 저장: SQLite `/var/lib/thing-data/db.sqlite3`와 `EC2_DATA_DIR` 파일 디렉터리
- 데이터 계약: 단일 로봇, UTC, `schema_version=1`, `data_version=1`, 공개 파일 정확히 네 개
- VCS/업무 관리: Git·GitLab, Jira, Notion

---

## 2. 주요 사용 시나리오

### UC-01-01. 실시간 손동작 모방(MIMIC 모드)

1. 사용자가 카메라 앞에 손을 위치시킨다.
2. 시스템이 손 landmark를 검출한다.
3. 시스템이 손가락별 굽힘값과 엄지 대립 및 벌림값을 계산한다.
4. 7논리축 목표값이 Raspberry Pi로 전달된다.
5. 로봇 손이 사용자의 손 자세를 따라 움직인다.
6. 카메라 프레임→landmark→7축→command manager 순서로 단계 수정

### UC-01-02. 웹 명령 기반 로봇 손 조작(MANUAL 모드)

1. 사용자가 내부망 관제·제어 웹에서 명령을 선택한다.
2. 7논리축 목표값이 Raspberry Pi로 전달된다.
3. 로봇 손이 전달된 목표값에 따라 움직인다.

### UC-02-01. 원통형 물체 파지(MIMIC 모드)

1. 원통형 물체를 로봇 손의 파지 영역에 배치한다.
2. 사용자가 손을 오므린다.
3. 로봇 손가락이 물체와 접촉한다.
4. 직렬 스프링이 추가 모터 이동을 흡수하며 물체를 누른다.
5. 로봇 손이 물체를 최소 3초 이상 유지한다.

### UC-02-02. 원통형 물체 파지(MANUAL 모드)

1. 사용자가 MANUAL 모드에서 원통형 물체 파지 명령을 선택한다.
2. 시스템이 사전에 정의된 7논리축 목표값을 생성한다.
3. Raspberry Pi가 명령의 유효성과 안전 상태를 검사한다.
4. 로봇 손가락이 원통형 물체를 감싸도록 움직인다.
5. 로봇 손이 물체를 최소 3초 이상 유지한다.

### UC-03. 엄지–검지 집기

1. 가벼운 소형 물체를 엄지와 검지의 집기 영역에 배치한다.
2. 사용자가 MIMIC 모드에서 집기 동작을 수행하거나 MANUAL 모드에서 집기 명령을 선택한다
3. 시스템이 엄지 굽힘·대립축과 검지 굽힘축의 목표값을 생성한다.
4. 엄지 끝과 검지 끝 또는 검지 측면이 물체에 접촉한다.
5. 로봇 손이 물체를 최소 3초 이상 유지한다.

> **사용 사례 번호 변경 기록:** 기존 UC-04(로컬 데이터 기록)는 기록부터 공개 조회까지의 단일 흐름을 만들기 위해 폐기했으며 이력 추적을 위해 번호를 재사용하지 않는다. 기존 UC-07(EC2 업로드)과 UC-08(EC2 조회·다운로드)은 각각 아래 UC-05의 B와 C로 통합했다.
> 

### UC-05. 실험 데이터 기록·직접 업로드·조회 및 다운로드

#### A. 로컬 기록

1. 사용자가 내부망 웹의 MIMIC 모드에서 기록 시작을 요청한다.
2. Logger가 0이 아닌 고유 `uint64` Session ID를 생성하고 rosbag2 기록을 시작한다. 활성 세션 상태는 실행 중 메모리와 RecordingState로만 관리한다.
3. Logger는 landmark, 최종 HandCommand, MotorStatus, ControlState, SafetyState와 기록 상태를 rosbag2에 저장하며 카메라 원본 영상은 저장하지 않는다.
4. 정상 종료 후 rosbag2를 닫고 실행 중 메모리에서 결과 판정을 기다린다. 사용자가 SUCCESS 또는 FAILURE를 판정하기 전에는 다음 정상 기록을 시작할 수 없다.
5. 안전 이벤트나 프로세스 종료로 중단된 rosbag2는 남기지 않는다.

#### B. EC2 직접 업로드

1. 판정 완료 직후 `thing-logger`의 exporter가 rosbag2를 읽어 metadata JSON, HandCommand CSV, MotorStatus CSV, LandMark JSON 를 세션별 임시 디렉터리에 생성한다.
2. exporter는 네 파일을 .part로 작성하고 schema·행 수·SHA-256을 검증한 뒤 최종 파일명으로 atomic rename한다. metadata에서 content_digest 필드만 제거한 canonical JSON byte와 세 데이터 파일의 고정 정보를 이용해 SHA-256 content_digest를 계산한다
3. exporter는 완료 디렉터리의 절대경로, 네 파일의 파일명·크기·행 수·SHA-256과 content_digest를 manifest로 구성하여 private Unix socket으로 uploader에 전달한다. uploader는 rosbag2에 접근하지 않으며, exporter는 네트워크 업로드와 EC2 응답 검증을 담당하지 않는다. uploader는 rosbag2에 접근하지 않는다.
4. uploader는 완료된 네 파일만 장치 Bearer Token과 HTTPS로 EC2 Django 업로드 API에 즉시 비동기 전송한다.
5. EC2는 STAGING에서 검증한 뒤 파일 디렉터리 이동과 SQLite 상태 전이로 READY만 공개한다.
6. 
- uploader는 handoff 요청을 수락하면 session_id, accepted, reason으로 구성된 ACK를 반환한다. ACK에는 content_digest를 포함하지 않는다.
- handoff 시도가 종료되면 exporter worker는 성공 여부와 관계없이 임시 canonical 네 파일을 정리한다. 완료된 원본 rosbag2는 삭제하지 않고 보존한다.
- MVP에서는 수동 재업로드 CLI, 영구 업로드 대기열, 자동 재시도 및 프로세스 재시작 후 실패 작업 복구를 제공하지 않는다.

> 여기서 “바로 업로드”는 기록 중 실시간 HTTP 전송이 아니라 **정상 종료와 판정 직후 시작하는 비동기 업로드**를 뜻한다.
> 

#### C. 공개 조회·다운로드

1. 외부 사용자는 로그인 없이 READY 세션 목록과 상세를 조회한다.
2. 기본 MVP는 Session ID·UTC 시각·결과와 7논리축·모터 데이터를 표 또는 기본 그래프로 확인한다.
3. 사용자는 metadata JSON, HandCommand CSV, MotorStatus CSV, LandMark JSON 정확히 네 파일을 다운로드한다.
4. EC2에서는 로봇 제어, 모드 변경, 기록 제어, Safety Reset과 rosbag2·상태 이력 공개를 제공하지 않는다.

표시 각도는 DYNAMIXEL encoder 기반 모터축 각도이며 실제 손가락 관절각이 아니다.

---

### UC-06. ROS 2 시스템 실행

1. 사용자가 Laptop의 내부 제어 웹 Vite 실행 명령, Jetson의 `docker run` 스크립트와 Raspberry Pi의 `docker compose up -d`를 실행한다.
2. Laptop은 `web/*~~internal-control/~~*frontend`의 React 화면을 제공하고, Jetson 컨테이너는 카메라·MediaPipe·MJPEG·Web Bridge**·Logger·exporter와 격리된 uploader**를, Raspberry Pi 컨테이너는 manager·guard·safety·DYNAMIXEL을 시작한다.
3. 모든 제어 노드는 이전 상태를 폐기하고 INIT에서 시작한다.
4. 사용자가 Laptop의 내부망 관제·제어 웹 또는 로컬 프로그램에서 제어 모드를 선택한다.
5. command manager가 현재 제어 모드와 제어권에 맞는 입력원 하나를 선택한다.
6. command guard가 선택된 명령의 timestamp, 범위, 속도 및 안전 상태를 검사한다.
7. 검증된 목표만 DYNAMIXEL 제어 노드에 전달한다.
8. 모터 상태, 제어 모드, 안전 상태 및 진단 정보를 ROS 2 토픽으로 발행하고 Jetson Web Bridge가 6.4절의 WebSocket snapshot으로 Laptop에 전달한다.
9. Jetson vision 실행 노드를 `camera_node`, `mediapipe_node`, `hand_target_node`, `mjpeg_streamer`, `web_bridge_node, logger`
    1. 격리 uploader는 launch 밖 별도 프로세스

제어 모드는 다음과 같이 구분한다.

- `DISABLED`: 일반 명령 비활성화
- `MIMIC`: MediaPipe 기반 실시간 손동작 모방
- `MANUAL`: 내부망 웹에서 Gesture 서비스와 Sequence 액션 실행
- `TELEOP`: 로컬 키보드 기반 개별축 조작

내부망 관제·제어 웹은 MIMIC과 MANUAL 모드 모두를 관제할 수 있다. 데이터 기록은 MIMIC 모드에서만 허용하며 기록 중에는 제어 모드를 변경할 수 없다.

---

## 3. 기능 요구사항

우선순위는 다음과 같이 구분한다.

- **Must:** 남은 2주 안에 통합·검수까지 반드시 완료할 기능
- **Should:** Must가 통과한 뒤 구현하며 단순화하거나 다음 스프린트로 이월할 수 있는 기능
- **Could:** 이번 2주 MVP 완료 조건에서 제외하고 시간이 남을 때만 진행할 기능

### 3.1 손 자세 인식

#### FR-01. 손 landmark 검출

**우선순위: Must**

시스템은 RGB 카메라에서 한 사용자의 오른손과 MediaPipe 21개 landmark를 검출해야 한다.

인수 조건:

- `HandLandmarks.detected`, `confidence`, `handedness`를 develop 인터페이스 그대로 발행한다.
- MIMIC 유효 기준은 `detected=true`, 오른손, `confidence>=0.70`이다.
- 손 미검출 또는 낮은 신뢰도가 150ms 연속되면 MIMIC HandCommand 발행을 중단하고 hand-loss latch를 설정한다.
- 명령 중단 뒤 FR-35의 300ms HOLD, 총 1000ms SAFE 정책이 동작해야 하며 미검출값을 새 정상 명령으로 대체하지 않아야 한다.
- 재검출은 위 유효 조건이 300ms 연속 유지되어야 인정한다. 재검출은 복구 조건 확인일 뿐 이전 명령이나 제어를 자동 재개하거나 즉시 latch를 해제하지 않는다.
- 이후 복구는 현재 SafetyState에 따라 FR-35만을 따른다. HOLD에서는 활성 mode·owner 아래 Guard 검증 activity가 최대 gap 100ms로 300ms 연속되면 RUN으로 자동복귀할 수 있다. 명시적 STOP을 선택한 경우 RESET→READY 뒤 mode·owner를 새로 획득한다. SAFE·FAULT·ESTOP에서는 원인 해소·안정 시간·`/thing/reset_safety`·INIT 재검사·READY 전환 뒤 mode·owner를 새로 획득한다.
- 모든 경로에서 활성화 이후 생성된 새로운 HandCommand만 실행하며 이전 command, Gesture, Sequence 및 recording을 자동 재개하지 않는다.
- 웹은 FR-27에 따라 미검출, latch, 현재 안전 상태와 필요한 복구 경로를 구분해 표시해야 한다.
- landmark overlay 품질 개선과 원시 좌표 상세 표시는 Should다.
- `camera_node`, `mediapipe_node`, `hand_target_node`
- 미검출 landmark 좌표는 유효값으로 사용하지 않음

#### FR-02. 손가락 굽힘값 계산

**우선순위: Must**

시스템은 검지, 중지, 약지, 소지 및 엄지의 landmark를 사용하여 각 손가락의 굽힘 정도를 계산해야 한다.

인수 조건:

- 각 손가락의 굽힘값을 `0.0~1.0` 범위로 표현해야 한다.
- `0.0`은 편 상태, `1.0`은 최대 굽힘 상태로 정의한다.
- 손 크기와 카메라 거리에 따른 영향을 최소화해야 한다.
- 비정상적인 계산 결과는 허용 범위 안으로 제한해야 한다.
- 손가락 굽힘·엄지 대립·벌림 계산 담당을 `hand_target_node`로 명시

#### FR-03. 엄지 대립 및 벌림값 계산

**우선순위: Must**

시스템은 엄지 끝과 검지, 중지 및 손바닥 landmark의 상대 관계를 이용하여 엄지 대립 및 벌림 정도를 계산해야 한다.

인수 조건:

- 엄지 대립 및 벌림값을 `0.0~1.0`으로 표현해야 한다.
- 엄지가 검지 방향으로 접근하는 움직임을 구분할 수 있어야 한다.
- 손의 크기를 기준으로 거리를 정규화해야 한다.
- 손가락 굽힘·엄지 대립·벌림 계산 담당을 `hand_target_node`로 명시

#### FR-04. 사용자 캘리브레이션

**우선순위: Should**

시스템은 사용자마다 다른 손가락 가동범위를 보정할 수 있어야 한다.

인수 조건:

- 사용자의 편 손 자세를 최소값으로 저장할 수 있어야 한다.
- 사용자의 주먹 자세를 최대값으로 저장할 수 있어야 한다.
- 저장된 값은 손가락별 정규화에 적용되어야 한다.
- 캘리브레이션은 내부망 관제·제어 웹에서 편 손과 주먹 자세를 수집·확인한 후 적용해야 한다.
- 사용자 캘리브레이션 적용 위치를 `hand_target_node`로 명시

---

### 3.2 명령 생성 및 전달

#### FR-05. 명령값 필터링

**우선순위: Must**

시스템은 손 떨림과 landmark 오차가 모터의 급격한 움직임으로 전달되지 않도록 목표값을 필터링해야 한다.

인수 조건:

- 작은 변화는 deadband를 통해 무시할 수 있어야 한다.
- 이동 평균 또는 저역 통과 필터를 적용해야 한다.
- 한 프레임에서 목표값이 급격하게 변경되지 않도록 제한해야 한다.
- deadband·저역 통과 필터·변화율 제한 담당을 `hand_target_node`로 명시

#### FR-06. ROS 2 손 명령 발행

**우선순위: Must**

`thing_vision/hand_target_node`는 7논리축 목표를 GitLab `develop`의 `HandCommand.msg`와 동일하게 `/thing/command/mimic`에 발행해야 한다.

기준:

- 브랜치: [develop/thing_interfaces](https://lab.ssafy.com/s15-webmobile3-sub1/S15P11C103/-/tree/develop/thing_ws/src/thing_interfaces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)
- 동결 커밋: `70dfdab8d555dfbfdd471c5acca4f30a8a8fc3ec`
- 경로: `/thing/command/mimic → command_manager → /thing/command/selected → command_guard → /thing/command`

인수 조건:

- `stamp`, source별 `sequence`, `source`, 7개 고정 축, `speed_limit`, `confidence`를 develop 정의 그대로 사용한다.
- `HandCommand`에는 mode·owner·enable 필드를 추가하지 않는다. mode·owner는 `SetControlMode`와 `ControlState`로만 관리한다.
- MIMIC 유효 명령은 20Hz 이상 발행하고, hand-loss latch 상태에서는 발행하지 않는다.
- 축 값과 confidence는 `0.0~1.0`의 유한값이어야 한다.
- 운영 `stamp`는 UTC와 동기화한 ROS system time을 사용한다.
- `speed_limit`은 MVP 프로젝트 규칙으로 `0.0 < value <= 1.0`만 허용하고 `0`은 invalid로 거부한다. 실제 축 속도는 YAML의 최대속도에 이 비율을 곱한다.

### 3.3 모터 제어

#### FR-07. 7채널 서보 제어

**우선순위: Must**

Raspberry Pi는 7개의 서보에 개별 목표 위치를 전달해야 한다.

인수 조건:

- 각 모터는 서로 다른 ID를 사용해야 한다.
- 손가락마다 최소 및 최대 모터 위치를 설정할 수 있어야 한다.
- 7개 모터에 서로 다른 목표값을 전달할 수 있어야 한다.
- 잘못된 목표값은 모터에 전달되기 전에 제한되어야 한다.

#### FR-08. 명령 보간 및 속도 제한

**우선순위: Must**

Raspberry Pi는 Jetson에서 전달된 목표값을 모터 제어 주기에 맞춰 부드럽게 보간해야 한다.

인수 조건:

- 목표 위치가 갑자기 변경되어도 모터가 즉시 최대 속도로 이동하지 않아야 한다.
- 손가락별 최대 속도를 설정할 수 있어야 한다.
- 엄지 대립 및 벌림축은 일반 손가락과 별도의 속도 제한값을 사용할 수 있어야 한다.

#### FR-09. 모터 상태 수집

**우선순위: Must**

시스템은 서보에서 제공하는 상태값을 수집해야 한다.

수집 대상:

- 실제 위치
- 목표 위치
- 속도
- 전류 또는 부하 추정값
- 온도
- 통신 상태

권장 토픽:

```
/thing/motor_status, /thing/diagnostics
```

`/joint_states`는 develop 인터페이스에 없으므로 2주 Must 경로에서 제외한다. 위치·속도·전류·온도·통신은 Must이며, 전압·hardware_error의 상세 UI 활용은 Should다.

#### FR-10. 초기화·명시적 정지 및 토크 정책

**우선순위: Must**

시작·재시작·모드 전환은 이전 명령을 재생하지 않아야 하며 토크 상태를 안전 상태 머신이 단일하게 결정해야 한다.

인수 조건:

- `INIT`: 캐시·sequence·실행 큐를 폐기하고 토크 OFF로 설정·E-Stop·7개 모터 통신을 검사한다.  Safety Reset 뒤에는 INIT 진입 이후 새 heartbeat만 검사에 사용할 수 있다.
- `READY`: 토크 OFF 상태로 새 mode·owner와 새 명령을 기다린다.
- `RUN`: 유효 mode·owner를 획득한 뒤 활성화 이후 첫 유효 명령에서만 토크 ON한다.
- `HOLD`: 현재 보간 setpoint에서 추가 이동을 멈추고 제한 토크를 유지한다.
- `SAFE`: 모터 통신·전류·온도가 정상일 때만 YAML 안전 자세로 저속 이동하고 도달 뒤 토크 OFF한다.
- `FAULT`: 일반 명령을 차단하고 토크 OFF한다.
- `ESTOP`: 물리 회로로 구동 전원을 차단한다.
- `RESET`: READY·RUN·HOLD의 정상 STOP 뒤 Guard latch를 닫고 현재 setpoint에서 `stop_settle_ms=500` 동안 안정화하며 torque OFF를 확인한다. RESET은 SAFE·FAULT·ESTOP의 Safety Reset 서비스와 다른 정상 제어 상태다.
- 명시적 STOP은 `SetControlMode(MODE_DISABLED, OWNER_NONE)`로 처리하며 READY·RUN·HOLD에서 RESET 경로로 허용한다. HOLD에서는 자동복귀와 명시적 STOP 중 하나를 선택할 수 있다.
- STOP service는 mode·owner·큐를 원자적으로 해제하고 `stop_requested`를 보낸 뒤 Guard의 `stop_barrier_ack`를 관측해야 성공한다. ACK timeout 시 성공으로 응답하지 않으며 DISABLED/NONE을 유지한다.
- RESET에서는 기존 보간 목표와 명령 큐를 폐기하고 YAML의 축별
home_position을 새로운 내부 목표로 설정한다.
- motor_driver_node는 reset_velocity_limit을 적용해 모든 필수 모터를
초기 자세로 복귀시킨다.
- 모든 모터가 position_tolerance 이내에 도달하고
stop_settle_ms=500 동안 안정적으로 유지되면 Torque를 OFF한다.
- 모든 MotorState에서 communication_ok=true 및
torque_enabled=false가 확인되면 READY로 전환한다.
- RESET은 정상 STOP과 제어권 전환을 위한 초기 자세 복귀 절차이며,
SAFE 상태의 안전 자세 이동과는 별개의 절차다.
- STOP 안정화 중 새 FAULT·ESTOP이 발생하면 해당 안전 상태가 우선한다. SAFE·FAULT·ESTOP에서 STOP은 mode=`DISABLED`, owner=`NONE`, `owner_alive=false`와 기존 큐만 원자적으로 해제하고 현재 안전 상태는 유지한다. 이 상태에서 READY 복귀는 원인 해소와 Safety Reset·INIT 재검사를 통해서만 허용한다.
- 시작, 컨테이너 재시작, 네트워크 복구와 E-Stop 물리 해제만으로 토크·mode·owner·명령·녹화를 자동 재개하지 않는다.

#### motor_driver_node 동작

| SafetyState | motor_driver_node 동작 |
| --- | --- |
| `INIT` | 명령 캐시 폐기, Torque OFF, 통신 및 설정 확인 |
| `READY` | Torque OFF, 명령 쓰기 금지 |
| `RUN` | 활성화 이후 새 명령이 들어온 경우만 Torque ON 및 제어 |
| `HOLD` | 현재 보간 setpoint 고정, 새 목표 적용 금지 |
| `SAFE` | 위험 상황에서 정의된 안전 자세로 이동 후 Torque OFF |
| `FAULT` | 일반 명령 폐기, Torque OFF |
| `ESTOP` | 명령 폐기, 물리 전원 차단 상태 관측 |
| `RESET` | 정상 제어 종료 및 제어권 전환을 위해 초기 자세로 복귀 후 Torque OFF |

SafetyState 결정은 safety_manager의 책임이고, 결정된 상태에 따른 실제 모터 동작은 motor_driver_node의 책임이다.

#### Reset 실패 처리

```yaml
RESET 중 필수 모터 통신 실패
→ FAULT

reset_motion_timeout_ms 안에 초기 자세 미도달
→ FAULT

초기 자세 도달 후 Torque OFF 실패
→ FAULT

RESET 중 E-Stop 발생
→ ESTOP 우선

RESET 중 새 mode/owner 획득 요청
→ 거부
```

### 3.4 안전 기능

#### FR-11. 명령 timeout 및 owner lease

**우선순위: Must**

Raspberry Pi는 monotonic clock으로 마지막 유효 명령과 owner lease를 서로 독립적으로 판정해야 한다.

```yaml
command_hold_timeout_ms: 300
command_safe_timeout_ms: 1000
control_renew_period_ms: 1000
owner_lease_timeout_ms: 3000
hand_confidence_min: 0.70
hand_loss_debounce_ms: 150
hand_reacquire_stable_ms: 300
stop_settle_ms: 500
fault_clear_stable_ms: 1000
estop_release_stable_ms: 500
safe_action_timeout_ms: 3000
```

- develop에는 전용 heartbeat/lease 메시지·서비스와 lease ID가 없다.
- 2주 MVP에서는 현재 owner가 동일한 mode·owner로 `/thing/set_control_mode`를 1000ms마다 재호출하면 READY·RUN·HOLD에서 lease를 갱신한다.  ****HOLD에서는 기존 owner의 동일 mode 갱신만 허용하고 새 owner·새 mode 획득과 motor forwarding은 금지한다. 이 호출은 명령 timeout을 갱신하지 않는다.
- 3000ms 동안 갱신이 없으면 하나의 임계구역에서 owner=`NONE`, mode=`DISABLED`, `owner_alive=false`로 바꾸고 Gesture·Action·명령 큐를 취소하며 활성 기록을 `INTERRUPTED`로 요청한다.
- lease 만료는 계획되지 않은 단절이므로 즉시 HOLD하고 마지막 유효 명령 기준 총 1000ms에 SAFE로 전환한다.
- 마지막 hardware-forwarded 유효 명령 후 300ms에 HOLD, 총 1000ms에 SAFE로 전환한다. HOLD에서는 활성 mode·owner와 fresh 상태 아래 Guard 검증 activity가 최대 gap 100ms로 300ms 연속일 때만 RUN으로 자동복귀하며, 이 activity는 motor로 전달하거나 SAFE 마감시각을 연장하지 않는다.
- MIMIC·TELEOP은 활성 동작 동안 신선한 stamp·증가 sequence의 HandCommand를 20Hz로 발행해야 한다. MANUAL Gesture는 동작·초기 유지시간이 끝나면 종료하며 마지막 자세를 무기한 재발행하지 않는다. Sequence는 구현하는 경우 각 단계 실행 중에만 같은 발행 규칙을 따른다.

#### FR-12. 안전 우선순위와 복구 원칙

**우선순위: Must**

안전 우선순위는 `ESTOP > FAULT > SAFE > HOLD > 일반 제어`로 고정하고 손 미검출을 포함한 모든 세부 전이와 복구 절차의 단일 기준은 FR-35로 한다.

- 안전 전이는 mode 변경, Logger 응답, 웹과 일반 명령보다 먼저 처리한다.
- HOLD·SAFE·FAULT·ESTOP에서 이전 큐와 stale command를 재실행하지 않는다.
- HOLD의 검증 activity 자동복귀와 SAFE·FAULT·ESTOP의 원인 해소·안정 시간·Safety Reset·`INIT`  새 입력 재검사·READY 전환은 FR-35의 절차만 따른다.
- `/thing/reset_safety`는 V7 MVP의 ROS 2 런타임 인터페이스 계약으로 확정한다. Raspberry Pi의 `thing_control` 패키지에 속한 `safety_manager`가 표준 `std_srvs/srv/Trigger` 서버를 제공하며 내부망에서만 사용하고 EC2·외부망에는 노출하지 않는다.
- 이 서비스는 커스텀 `thing_interfaces` 타입이 아니다. `thing_interfaces/srv/ResetSafety.srv`와 인터페이스 생성 항목을 추가하지 않으며 기존 7 msg·5 srv·1 action 구성을 유지한다.
- 서비스 서버와 8상태 정책은 `thing_control`에 구현한다. 실제 GPIO·motor publisher·trip limit 실물 검증은 hardware 통합 후 완료한다.
- Reset 요청이 수락되면 reset 직전 cache를 폐기하고 INIT 재검사를 시작한다. INIT 진입 이후 새 MotorStatus와 새 E-Stop heartbeat를 모두 받아 검사를 통과해야 READY가 되며, 토크 OFF, mode= `DISABLED`, owner= `NONE`을 유지한다. 새 활성화와 새 명령이 있어야 RUN으로 전환한다.
- FAULT와 ESTOP 조건이 같은 executor 구간에서 경쟁할 때 ESTOP을 우선한다. lower-priority FAULT 상태 발행은 E-Stop callback에 우선권을 주기 위해 tick 1회(기본·최대 20ms)만 보류할 수 있고 ESTOP은 즉시 발행한다.

#### FR-13. 물리적 비상정지와 상태 감지

**우선순위: Must**

ROS 2·CPU와 무관하게 모터 구동 전원을 차단하는 물리적 E-Stop을 제공해야 한다.

- 전원 차단 주접점과 별도 NC 보조접점을 사용하고 보조접점은 절연 GPIO로 읽는다.
- 보조접점 단선·읽기 불가는 E-Stop active로 처리한다.
- CPU가 동작 중이면 작동 후 100ms 안에 `SafetyState.estop_active=true`와 ESTOP을 발행한다.
- 물리 해제는 복구 요청이 아니며 `estop_release_stable_ms=500`의 연속 안정과 Safety Reset·INIT 재검사가 필요하다.

#### FR-14. 모터 fault 판정

**우선순위: Must**

과전류·과온·지속 통신 오류와 SAFE 동작 실패를 latch FAULT로 처리해야 한다.

- 단일 읽기 실패는 경고로 기록한다.
- 필수 모터의 `communication_ok=false`가 3회 연속이거나 `bus_communication_ok=false`가 300ms 연속이면 지속 통신 오류로 판정한다.
- DYNAMIXEL 자체 shutdown 보호를 비활성화하지 않는다.
- 전류·온도 trip 값은 XL330-M288-T 제조사 범위 이하에서 실물 부하 시험으로 확정해 YAML에 저장한다. 검증값이 없거나 범위를 벗어나면 INIT을 실패 처리한다.
- fault 원인이 1000ms 이상 해소되기 전 Reset을 거부하며, FAULT에서 자율 자세 이동을 시도하지 않는다.

### 3.5 파지 기능

#### FR-15. 편 손과 주먹 동작

**우선순위: Must**

로봇 손은 사용자의 손동작 또는 사전 정의된 명령을 통해 편 손과 주먹 자세를 수행해야 한다.

인수 조건:

- 모든 손가락이 시각적으로 구분 가능한 편 손 자세를 만든다.
- 모든 손가락이 주먹 방향으로 굽혀진다.
- 편 손에서 주먹, 주먹에서 편 손으로 반복 전환할 수 있다.

#### FR-16. 원통형 물체 파지

**우선순위: Must**

로봇 손은 손바닥과 여러 손가락을 이용해 가벼운 원통형 물체를 파지해야 한다.

인수 조건:

- 지정된 위치에 놓인 원통형 물체를 감쌀 수 있어야 한다.
- 물체를 최소 3초 이상 유지해야 한다.
- 동일 물체를 10회 시험하여 7회 이상 성공해야 한다.

#### FR-17. 집기

**우선순위: Must**

로봇 손은 엄지 굽힘 및 대립축과 검지를 이용해 가벼운 소형 물체를 집어야 한다.

인수 조건:

- 엄지 끝과 검지 끝 또는 검지 측면이 접촉해야 한다.
- 물체를 최소 3초 이상 유지해야 한다.
- 지정된 물체를 10회 시험하여 7회 이상 성공해야 한다.

---

### 3.6 데이터 저장

#### FR-18. 실험 데이터 기록 및 세션 수명주기

**우선순위: Must**

Logger는 rosbag2를 로봇의 유일한 로컬 시계열 원본으로 사용하며 별도의 애플리케이션 SQLite,
`session_state.json` 및 영구 upload outbox를 만들지 않는다.

필수 rosbag2 기록 토픽:

- `/thing/landmarks`
- 최종 `/thing/command`
- `/thing/motor_status`
- `/thing/control_state`
- `/thing/safety_state`
- `/thing/recording_state`

`/thing/start_recording`과 `/thing/stop_recording`은 기록 토픽이 아니라 Web Bridge가 호출하는
ROS 2 서비스다.

세션의 시작·종료 시각은 별도의 start/stop 토픽으로 기록하지 않는다.
Logger는 시작·종료 시각과 Session ID, bag path, 기록 상태를 실행 중 메모리와
`/thing/recording_state`로 관리한다.

실행 중 상태 관리:

- 활성 Session ID, bag path, UTC 시작·종료, 기록·판정 대기 상태는 Logger 메모리와 RecordingState로 관리한다.
- 업로드 성공·실패는 uploader 진단 로그에 기록하고 최종 공개 상태는 EC2 GET API에서 확인한다.

세션 규칙:

- Session ID는 CSPRNG로 만든 0이 아닌 63-bit 양의 정수로 생성해 ROS `uint64`에 담고 기존 rosbag2 경로 충돌을 검사한다. JSON·API·EC2에서는 10진 문자열로 표현한다.
- 기록은 MIMIC에서 동시에 하나만 허용한다. StartRecording은 고유 경로 확보와 rosbag2 시작이 모두 성공해야 수락한다.
StartRecording은 SafetyState가 READY 또는 RUN이고 활성 기록과 결과 판정 대기 세션이 없으며, 고유 Session ID·bag 경로 확보와 rosbag2 writer 시작 및 필수 토픽 등록이 모두 성공한 경우에만 수락한다. 조건을 만족하지 않으면 상태에 따라 `not_mimic_mode`, `start_failed`, `already_recording` 또는 `result_pending`으로 거부한다.
- 정상 Stop은 rosbag2를 flush·종료하고 실행 중 메모리에서 결과 판정을 기다린다. 결과 수락 직후 exporter를 시작하며 판정 전 다음 정상 기록을 거부한다.

→ StopRecording은 현재 RECORDING 상태의 활성 Session ID와 요청 Session ID가 일치할 때만 수락한다. 기록 중이 아니면 `not_recording`, Session ID가 다르면 `session_mismatch`로 거부한다. 정상 Stop은 rosbag2를 flush·종료한 뒤 `COMPLETED`, `result_pending=true`로 전환하며 판정 전 다음 정상 기록을 거부한다. flush 또는 writer close가 실패하면 `stop_failed`를 반환하고 해당 bag 삭제를 시도한 뒤 세션을 `INTERRUPTED`로 종료한다.

- 카메라 원본 영상은 저장하지 않는다.
- SAFE·FAULT·ESTOP·lease 만료·프로세스 종료 시 안전 전이를 먼저 수행하고 가능한 즉시 rosbag2를 flush한다.

→SAFE·FAULT·ESTOP, MIMIC 모드 이탈, owner lease 만료, rosbag2 write 오류 및 프로세스 종료 시 활성 세션을 `INTERRUPTED`로 종료한다. Logger는 writer의 flush·종료와 해당 bag 삭제를 가능한 즉시 시도한다. 삭제 실패는 진단 로그에 남기되 제어·안전 동작을 차단하지 않는다. INIT 동안 `INTERRUPTED`를 유지하고 SafetyState.READY 수신 후 `IDLE`로 전환하며 이전 recording은 자동 재개하지 않는다.

- 프로세스 재시작 뒤 이전 recording·판정 대기·upload를 자동 복원하거나 재개하지 않는다. 남은 rosbag2는 수동 확인·재업로드의 원본으로만 사용한다.
- rosbag2·exporter·uploader I/O는 제어 callback과 분리한다. 기록 디스크가 불가하면 새 recording만 거부하고 제어·안전은 계속한다.
- `/thing/landmarks`는 기록하지만 `/thing/image_raw`와 MJPEG 영상은 저장하지 않는다.

### 3.7 내부망 관제·제어 웹 기능

#### FR-19. 웹 모드 선택

**우선순위: Must**

웹은 MIMIC과 MANUAL을 선택하고 현재 mode·owner를 `/thing/control_state`로 확인해야 한다.

- mode·owner는 `HandCommand`에 포함하지 않고 `/thing/set_control_mode`로만 요청한다.
- MIMIC↔MANUAL 직접 전환은 금지한다. 먼저 `MODE_DISABLED, OWNER_NONE`으로 STOP한 뒤 READY에서 새 mode·owner를 획득한다.
- 기록·Gesture·Action 중 새 일반 mode 요청은 거부하되  READY·RUN·HOLD의 STOP과 안전 전이는 항상 선점한다. HOLD에서는 기존 owner의 recovery authority를 보존하지만 사용자의 명시적 STOP은 FR-35의 RESET 경로로 허용한다.
- 동시에 온 요청은 command manager의 단일 mutex에서 직렬화하며 첫 유효 요청 하나만 수락한다. 다른 owner, stale owner, 안전 비정상 요청은 거부하고 현재 ControlState를 유지한다.
- hand-loss latch 뒤 단순 재검출만으로는 재개하지 않는다. SafetyState가 HOLD이면 기존 MIMIC mode·owner 아래 새 명령이 Guard 전체 검증을 통과해 최대 gap 100ms로 300ms 연속될 때만 RUN으로 자동복귀한다. SAFE·FAULT·ESTOP이면 Safety Reset·INIT·READY 뒤 DISABLED→MIMIC의 새 획득을 수행한다.

#### FR-20. 모방 모드 영상 표시

**우선순위: Must**

웹은 저장하지 않는 MJPEG 영상, 손 검출 여부와 hand-loss·재개 필요 상태를 표시해야 한다. landmark overlay의 정교한 표현은 Should다.

`mjpeg_streamer`가 image와 landmark를 합성해 HTTP MJPEG를 제공.

#### FR-21. 모방 모드 손동작 정보 표시

**우선순위: Should**

5개 손가락 굽힘, 엄지 대립·벌림, 7논리축 목표와 confidence를 숫자 또는 게이지로 표시한다. 원시 landmark 좌표 표시는 Could다.

구조화된 landmark·7축 정보는 `web_bridge_node`가 WebSocket으로 제공

#### FR-22. 조작 모드 명령 입력

**우선순위: Must**

MANUAL에서 편 손, 주먹, 원통 파지, 집기, STOP을 사전 정의 7축 값으로 실행해야 한다.

- 같은 시점에 Gesture 하나만 실행하고 새 일반 동작은 큐에 쌓지 않고 거부한다.
- Gesture executor는 동작·초기 유지 중 20Hz의 새 HandCommand를 발행한다. 기본 동작·초기 유지시간은 open·fist 1000ms, cylindrical_grasp·pinch 3000ms이며 YAML에서 변경한다.
- 초기 유지시간이 끝나면 Gesture는 완료하며 마지막 자세를 새 stamp·sequence로 무기한 재발행하지 않는다. 다음 자세는 새 Gesture 요청으로만 생성한다.
- 새 Gesture는 기존 실행을 교체하지 않고 실행 중이면 거부한다. owner lease 만료·HOLD·SAFE·FAULT·ESTOP은 현재 executor를 즉시 취소한다. 현재 MVP에서 MANUAL HOLD는 executor가 recovery-only activity를 합성하지 않으며, 사용자는 명시적 STOP을 선택하거나 총 1000ms SAFE 상승 뒤 Safety Reset 절차를 따른다.
- STOP은 FR-10의 DISABLED 전환이며 다른 일반 동작을 선점한다.
- 가위바위보·카운트다운 Sequence와 별도 초기 자세 버튼은 Could다.

#### FR-23. 웹 명령 범위 제한

**우선순위: Must**

웹은 허용된 gesture·mode enum만 전송하고 임의 축·모터 ID·ROS 이름을 입력받지 않아야 한다. 서버와 command_guard가 유한값, 범위, speed_limit, timestamp, sequence를 다시 검증한다.

#### FR-24. 로봇 및 시스템 상태 모니터링

**우선순위: Must**

웹은 Jetson·Raspberry Pi·ROS 2·카메라·모터 연결, active mode·owner, SafetyState와 RecordingState를 구분해 표시해야 한다. 모터별 watchdog·원시 진단 상세 화면은 Should다.

camera·MediaPipe·hand_target·MJPEG 연결 상태를 각각 구분해 표시

#### FR-25. 모터 상태 표시

**우선순위: Should**

7개 모터의 목표·현재 위치, 속도, 전류, 온도와 통신 상태를 구분하고 stale 값은 연결 끊김과 구별해야 한다. 이 화면은 Raspberry Pi의 안전 판단을 대신하지 않는다.

#### FR-26. 데이터 기록 UI 및 상태 표시

**우선순위: Must**

웹은 develop의 StartRecording·StopRecording·SetMimicResult 서비스만 호출하고 RecordingState로 Session ID·상태·판정 대기를 표시해야 한다.

- 웹은 rosbag2·임시 업로드 파일·EC2 SQLite를 직접 생성·수정·삭제하지 않는다.
- 내부망 웹의 실시간 영상·상태는 MJPEG와 Web Bridge WebSocket을 통해 ROS 2에서 받고 rosbag2나 DB를 조회하지 않는다.
- `bag_path`는 로컬 rosbag2가 활성화된 정상 세션 경로이며 EC2 upload 상태를 뜻하지 않는다.
- develop RecordingState에는 upload 필드가 없으므로 업로드 진행률은 ROS 계약에 추가하지 않고 uploader 진단 로그로만 확인한다. 완료된 공개 세션은 EC2 포털의 GET API에서 조회한다.
- 영상은 MJPEG HTTP, 상태 데이터는 WebSocket이라는 경로 분리

#### FR-27. 웹 오류 및 안전 안내

**우선순위: Must**

웹은 손 미검출, 연결 단절, timeout, 모터 통신, 과전류·과온, E-Stop과 reset 가능 여부를 설명하고 위험 상태에서 일반 조작을 비활성화해야 한다.

- 손 미검출과 유효 재검출 300ms를 표시하되 재검출이나 연결 복구만으로 제어가 재개된 것처럼 표시하지 않는다.
- 현재 SafetyState가 HOLD이면 Guard 검증 activity 300ms 자동복귀 조건, 100ms 최대 gap, 총 1000ms SAFE deadline과 명시적 STOP→RESET 대안을 함께 안내한다. MANUAL은 현재 recovery activity를 자동 생성하지 않으며 단순 연결 복구를 RUN으로 표시하지 않는다.
- 현재 SafetyState가 SAFE·FAULT·ESTOP이면 원인 해소와 설정된 안정 시간 뒤 `/thing/reset_safety`가 필요함을 안내하고, INIT 재검사와 READY 전환 전에는 MIMIC 재활성화를 허용하지 않는다.
- reset 가능 여부와 거부 사유를 구분하고, 복구 완료 뒤에도 새 MIMIC·owner 획득과 새 HandCommand가 필요함을 표시한다.
- hand-loss latch는 develop ROS 2 메시지에 필드를 추가하지 않고 HandLandmarks·SafetyState·ControlState를 바탕으로 Web Bridge가 파생한 WebSocket 표시 상태로만 제공한다.
    - 상세 복구 순서의 단일 기준은 FR-35이며 이전 command, Gesture, Sequence 및 recording을 자동 재개하지 않는다.
- Web Bridge가 `/thing/landmarks`를 직접 구독해 hand-loss 상태를 계산

#### FR-28. 내부망 관제·제어 웹 실행 환경 제한

**우선순위: Must**

내부 제어 웹의 Vite+React frontend는 Laptop에서 실행하고 프로젝트 내부망에서만 제공한다. frontend는 `web/*~~internal-control/~~*frontend`에 두며 `WS_URL`과 `MJPEG_URL` 외부 설정으로 Jetson Web Bridge와 MJPEG에 연결한다. 외부 인터넷에서 접근 가능한 로봇 제어 API를 만들지 않으며 EC2 데이터 포털은 별도 읽기 전용 시스템이다.

`MJPEG_URL`이 `mjpeg_streamer`의 HTTP endpoint를 가리킴

---

### 3.8 ROS 2 시스템 및 인터페이스

#### FR-29. ROS 2 패키지 모듈화

**우선순위: Should**

기존 `thing_interfaces`, `thing_description`, `thing_vision`, `thing_control`, `thing_hardware`, `thing_teleop`, `thing_logger`, `thing_web_bridge`, `thing_bringup` 책임을 유지한다. Must 구현에 필요한 안전·제어·기록 격리는 지키되 추가 패키지 분할과 리팩터링은 Must 통합 뒤 진행한다.

- Laptop: `web/*~~internal-control/~~*frontend`의 내부 제어 Vite+React 화면
- Jetson: vision·MJPEG·Web Bridge, thing_logger(logger·exporter·격리 uploader)
- Raspberry Pi `thing-control`: command manager·guard, safety, DYNAMIXEL
- Raspberry Pi `thing-data-uploader`: 완료된 임시 네 파일의 HTTPS upload만 담당
- EC2: `EC2/frontend`와 `EC2/backend`로 구성하며 ROS 2와 분리
- `thing_vision`의 3개 vision 관련 노드와 `thing_web_bridge`의 2개 노드 책임 구분

#### FR-30. 사용자 정의 ROS 2 인터페이스 동결

**우선순위: Must**

ROS 2 스키마의 단일 기준은 [GitLab develop의 thing_interfaces](https://lab.ssafy.com/s15-webmobile3-sub1/S15P11C103/-/tree/develop/thing_ws/src/thing_interfaces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)이며 이 문서 검증 커밋은 `70dfdab8d555dfbfdd471c5acca4f30a8a8fc3ec`이다.

- 메시지 7종: `HandCommand`, `HandLandmarks`, `MotorState`, `MotorStatus`, `ControlState`, `SafetyState`, `RecordingState`
- 서비스 5종: `SetControlMode`, `ExecuteGesture`, `StartRecording`, `StopRecording`, `SetMimicResult`
- 액션 1종: `ExecuteSequence`

이 문서에는 필드 원문을 복제하지 않는다. 이름·타입·상수·필드 순서는 위 커밋의 `.msg/.srv/.action` 파일을 그대로 사용하며 6.3절은 런타임 이름만 정의한다.

v7에서 승인된 변경 사항: 

- `SafetyState.msg`: 기존 상수 뒤 `uint8 RESET=7` 추가. 기존 상수 번호와 필드 순서는 변경하지 않는다.
- `MotorState.msg`: motor별 torque OFF 확인을 위한 `bool torque_enabled` 추가.

`/thing/reset_safety`는 프로젝트의 ROS 2 런타임 서비스 계약에는 포함되지만 커스텀 `thing_interfaces` 구성에는 포함되지 않는다. ROS 2 표준 `std_srvs/srv/Trigger`를 사용하므로 `thing_interfaces/srv/ResetSafety.srv`를 만들거나 `thing_interfaces/CMakeLists.txt`의 인터페이스 생성 목록을 변경하지 않는다.

프로젝트 의미 규칙:

- `HandCommand`는 7개 고정 축·source·sequence·speed_limit·confidence이며 mode·owner·enable이 없다.
- `ControlState`만 active mode·owner·owner_alive·sequence_running을 나타낸다.
- `RecordingState.bag_path`는 로컬 rosbag2 경로이며 EC2 상태가 아니다.
- `SafetyState.RESET`은 명시적 정상 STOP의 Guard ACK·settle·torque-off 확인 상태다. `/thing/reset_safety` 요청명과 같은 단어를 쓰지만 서로 다른 절차다.
- `MotorState.torque_enabled`는 READY/FAULT/RESET의 torque-off 검증에 사용하며 실제 hardware publisher가 모터별 readback을 채워야 한다.
- `SafetyState.fault_code` 코드표, speed_limit 의미와 reason 문자열은 develop 스키마에 없으므로 FR-41 프로젝트 설정·문서로 고정한다.
- `/thing/image_raw`가 표준 `sensor_msgs/msg/Image`임

#### 변경사항:

- `MotorState` 메시지의 `float32 temperature_celsius`  다음 줄에 `bool torque_enabled` 를 추가한다.
    
    인수조건:
    
    - `torque_enabled=true`: 모터 Torque Enable 레지스터가 활성화된 상태
    - `torque_enabled=false`: Torque Enable 레지스터가 비활성화된 상태
    - 해당 주기 통신 실패 시 `torque_enabled`를 유효한 상태로 해석하지 않고 `communication_ok=false`를 우선 확인
    - Torque 제어 명령은 `MotorState`로 보내지 않으며, 별도의 서비스 또는 안전 제어 인터페이스로 정의

#### FR-31. 명령 중재와 충돌 처리

**우선순위: Must**

`command_manager`만 MIMIC·TELEOP·MANUAL 중 active mode·owner에 맞는 하나를 `/thing/command/selected`로 발행한다.

- mode·owner 획득·갱신·해제는 하나의 mutex/atomic transaction에서 처리한다.
- owner=`NONE`에서 첫 유효 획득 요청 하나만 수락한다. 같은 owner·mode 재요청은 lease 갱신, 다른 owner 요청은 거부다.
- mode 전환은 반드시 DISABLED를 거친다. 기록·Gesture·Action 실행 중 새 일반 요청은 거부한다.
- Gesture와 Action은 동시에 실행하지 않으며 새 일반 동작은 큐에 쌓지 않는다.
- STOP, lease 만료와 SafetyState 전이는 일반 동작을 선점하고 선택·최종 큐를 함께 폐기한다.
- 안전 전이와 일반 요청이 동시에 발생하면 안전 전이가 이긴다. STOP과 새 동작이 동시에 발생하면 STOP이 이긴다.
- `command_manager`가 `/thing/command/mimic`을 구독

#### FR-32. 명령 검증 및 최종 모터 명령

**우선순위: Must**

`command_guard`만 `/thing/command/selected`를 검증해 `/thing/command`로 발행한다.

검증:

- 유한값, 축·confidence `0.0~1.0`, speed_limit `0.0 초과 1.0 이하`
- source와 active mode 일치
- ROS stamp가 미래 100ms를 넘지 않고 수신 시점 기준 300ms보다 오래되지 않음
- source별 sequence가 새 값임
- 축별 위치·속도·변화율과 SafetyState

sequence는 active source별로 관리한다. 새 mode 획득 때 해당 source 기준을 초기화하고, active 동안에는 uint32 serial-number 비교로 전진만 허용해 wrap을 처리한다. 단순 프로세스 재연결은 초기화 조건이 아니며 DISABLED 재획득이 필요하다.

STOP·Safety Reset은 HandCommand가 아니므로 이 토픽에 가짜 명령으로 넣지 않는다.

#### FR-33. 최신 목표 추종과 하드웨어 watchdog

**우선순위: Must**

DYNAMIXEL 노드는 콜백에서 `latest_target`만 원자적으로 갱신하고 제어 타이머가 최신 목표를 보간한다.

- 이전 목표 완료 전 새 목표를 처리하고 stale 목표를 큐에 쌓지 않는다.
- Raspberry Pi 내부 `hardware_command_watchdog_ms=500`에서 새 최종 명령이 없으면 추가 이동을 중단한다.
- hardware watchdog은 std::chrono::steady_clock을 사용한다.
- 명령 callback은 latest_target과 마지막 수신 시각만 갱신한다.
- 50Hz 제어 루프와 watchdog은 상태 읽기 및 일반 ROS callback 지연으로부터 분리된 전용 thread를 사용하거나, 별도 callback group을 MultiThreadedExecutor의 독립 실행 thread에 배치한다.
- 마지막 최종 명령 이후 500ms가 지나면 추가 위치 갱신을 중단한다.
- DYNAMIXEL Bus Watchdog 레지스터 적용은 실물 모델·제어주기 검증 후 Should로 진행한다.

#### FR-34. 제어 모드 및 owner lease

**우선순위: Must**

develop의 `MODE_DISABLED|MIMIC|MANUAL|TELEOP`와 `OWNER_NONE|WEB|LOCAL` 상수를 사용한다.

- MIMIC은 mimic, MANUAL은 Gesture·Sequence의 manual, TELEOP은 teleop 입력만 허용한다.
- 획득: READY에서 `SetControlMode(활성 mode, WEB|LOCAL)`.
- 갱신: 현재 owner가 같은 mode·owner 요청을 1000ms마다 보낸다.
- 정지·해제: `SetControlMode(MODE_DISABLED, OWNER_NONE)`. 누구나 내부망에서 안전 정지를 요청할 수 있으나 활성 mode 획득은 owner 충돌 검사를 거친다. STOP의 상태별 처리와 READY 복귀 조건은 FR-35를 따른다.
- 3000ms lease 만료 시 FR-11의 원자적 해제와 안전 전이를 적용한다.
- `ControlState.owner_alive`는 유효 lease일 때만 true다.

#### FR-35. 안전 상태 관리와 복구 절차

**우선순위: Must**

develop `SafetyState`의 `INIT, READY, RUN, HOLD, SAFE, FAULT, ESTOP, RESET` 의 8개 상태를 사용하며 이 절을 안전 전이와 복구 절차의 단일 기준으로 한다.

기본 전이:

- 시작·재시작 → `INIT`: torque OFF, cache·queue 폐기, 설정·E-Stop·7모터 검사
- INIT 정상 → `READY`: torque OFF, 새 mode·owner 획득 대기
- READY + 유효 mode·owner 획득 뒤 활성화 이후 첫 새 명령 → `RUN`
- RUN + 마지막 hardware-forwarded 명령 300ms 단절 → `HOLD`: 현재 보간 setpoint 고정
- RUN/HOLD + 마지막 hardware-forwarded 명령 기준 총 1000ms 단절 → `SAFE`: 건강한 모터만 저속 안전 자세, 성공 뒤 torque OFF
- READY·RUN·HOLD의 명시적 STOP + Guard ACK → `RESET`
- RESET에서 500ms 안정 + 모든 motor `torque_enabled=false` → `READY`
- 과전류·과온·필수 모터 통신 실패 3회 연속·bus 통신 실패 300ms 연속·SAFE 3000ms 실패 → `FAULT`
- E-Stop active 또는 E-Stop 입력 불명 → `ESTOP`

`safety_manager`의 SAFE 완료 관측은 local receipt가 SAFE 전환 뒤이고 source stamp가
SAFE 전환 system timestamp보다 새로운 정상 `MotorStatus`에서 7개 motor의
`torque_enabled=false`가 모두 확인되는 조건이다. `safe_action_timeout_ms` 기본·최대값은
3000ms이며, 진입 전 cache와 늦게 도착한 진입 전 측정값은 source stamp가 이전이므로
완료 증거로 재사용하지 않는다.
안전 자세 명령 생성·저속 이동·torque-off 수행 자체는 `thing_hardware` 책임이다.

HOLD 자동복귀:

1. HOLD 중에도 Manager는 기존 활성 mode·owner를 보존하되 Guard만 복구 후보 명령을 검증한다.
2. Guard는 source·stamp·sequence·유한값·축 범위·변화율·SafetyState·ControlState freshness를 모두 검사한다.
3. 통과한 명령은 단일 ordered `/thing/command/validation_result`에 `std_msgs/msg/Bool(data=true)`로 알리고 `/thing/command`로 motor에 전달하지 않는다.
4. validated activity가 최대 gap 100ms로 300ms 연속이면 Safety Manager가 HOLD→RUN으로 자동복귀한다.
5. 간헐 activity 또는 검증 실패가 있으면 연속 구간을 초기화한다. Guard는 실패를 같은 `/thing/command/validation_result`에 `data=false`로 알린다. 성공·실패는 한 publisher의 단일 ordered topic으로 전달하며, activity는 마지막 hardware-forwarded 명령 기준 총 1000ms SAFE deadline을 갱신하지 않는다.
6. HOLD 중 명시적 STOP은 허용한다. Guard ACK 뒤 RESET으로 전환해 timeout 기반 SAFE 상승을 취소하고 정상 torque-off 절차를 수행한다.

명시적 정상 STOP:

1. 사용자가 `SetControlMode(MODE_DISABLED, OWNER_NONE)`을 요청한다.
2. Command Manager는 한 임계구역에서 mode=`DISABLED`, owner=`NONE`, `owner_alive=false`로 만들고 command·Gesture·Sequence queue를 폐기한다.
3. Manager는 `/thing/control/stop_requested`를 발행하고 Guard는 먼저 STOP latch와 activation trust를 닫은 뒤 `/thing/control/stop_barrier_ack`를 발행한다.
4. Manager는 ACK를 관측한 뒤에만 service `accepted=true`를 반환한다. 기본 300ms·최대 500ms 안에 ACK가 없으면 `accepted=false`, `reason=stop_barrier_timeout`을 반환하고 DISABLED/NONE과 재획득 차단을 유지한다.
5. Safety Manager는 Guard ACK를 READY·RUN·HOLD에서 수락해 `RESET`으로 전환한다.
6. RESET에서는 command timeout 기반 SAFE timer를 취소하고 현재 setpoint에서 500ms 안정화한 뒤 모든 motor torque OFF를 확인한다. 성공하면 READY, timeout·hardware fault·E-Stop이면 FAULT 또는 ESTOP으로 선점한다.
7. 정상 STOP 뒤 제어권 재획득은 STOP system timestamp보다 source stamp가 새로운 RESET과 그보다 새 stamp의 READY를 순서대로 관측한 뒤에만 허용한다. STOP 뒤 FAULT가 RESET을 선점한 경우에는 새 Safety Reset의 INIT→READY epoch를 인정한다.
8. SAFE·FAULT·ESTOP의 STOP은 Manager의 mode·owner·queue만 해제하며 SafetyState를 바꾸지 않는다. READY 복귀는 아래 Safety Reset만 허용한다.

SAFE·FAULT·ESTOP의 Safety Reset:

1. 손 미검출, 통신 오류, 과전류·과온, E-Stop 등 진입 원인을 해소한다.
2. SAFE·FAULT 원인은 해소 뒤 1000ms, E-Stop은 물리 해제 뒤 500ms 연속 안정해야 한다. 원인이 여러 개면 모든 조건을 만족한다.
3. 내부망에서 `/thing/reset_safety`를 호출한다. HOLD·READY·RUN·RESET에서는 이 서비스를 거부한다.
4. 조건이 부족하면 `success=false`와 이유를 반환하고 현재 상태를 유지한다.
5. 수락하면 `success=true`를 반환하고 INIT에 진입한다. 이 응답은 INIT 통과나 READY 도달을 뜻하지 않는다.
6. reset 직전 MotorStatus·E-Stop cache는 INIT 통과에 사용하지 않는다. INIT 진입 이후 새 MotorStatus와 새 E-Stop heartbeat를 모두 받아 설정·통신·torque-off를 다시 확인한다.
7. 통과하면 torque OFF·mode=`DISABLED`·owner=`NONE`인 READY가 된다. 이후 새 mode·owner와 활성화 이후 새 명령이 필요하다.

lease 및 우선순위:

- owner lease 만료 시 Manager는 owner·mode·queue를 원자적으로 해제하고 `ControlState.last_transition_reason=owner_lease_expired`를 발행한다. 같은 service 요청 안에서 lease 만료와 재획득을 함께 처리하지 않고 현재 요청을 `owner_lease_expired`로 거부한다. Safety Manager는 RUN에서 이를 받는 즉시 HOLD로 전환하며 command 300ms timeout을 기다리지 않는다.
- 우선순위는 `ESTOP > FAULT > SAFE > HOLD > 일반 제어`다. E-Stop active는 모든 상태를 즉시 선점한다.
- lower-priority FAULT 발행은 이미 도착 가능한 E-Stop callback 처리를 위해 tick 1회(기본·최대 20ms)만 coalesce한다. window 안 ESTOP이면 FAULT를 외부에 먼저 발행하지 않고 ESTOP을 즉시 발행하며, ESTOP이 없으면 deadline에 FAULT를 발행한다.

복구 공통 규칙:

- 안전 전이 시 이전 command·Gesture·Sequence queue를 폐기하고 활성 recording을 `INTERRUPTED`로 종료한다.
- 이전 command, Gesture, Sequence와 recording은 어떤 경로에서도 자동 재개하지 않는다.
- 안전 자세와 torque override는 Raspberry Pi의 Safety Manager와 hardware node 내부 경로로 적용한다. develop에 없는 `/thing/command/safety`를 만들지 않으며 `SOURCE_SAFETY`는 향후 확장을 위해 예약한다.

#### FR-36. ROS 2 토픽 및 QoS

**우선순위: Must**

토픽 이름·타입의 단일 기준은 6.3절이다.

- develop 확정: `/thing/landmarks`는 sensor data/Best Effort, 최종 `/thing/command`는 Reliable depth 1, `/thing/safety_state`와 `/thing/recording_state`는 Reliable·Transient Local, diagnostics는 1Hz 이상
- MVP 프로젝트 기본: 다른 command 토픽은 Reliable depth 1, MotorStatus는 Reliable depth 5, ControlState는 Reliable·Transient Local
- develop에서 미확정인 QoS를 “GitLab 확정값”으로 표현하지 않으며 실물 조정 결과는 `docs/interfaces.md`와 YAML에 함께 반영한다.
- `/thing/image_raw` 타입과 QoS 추가

#### FR-37. 제어 모드 서비스

**우선순위: Must**

`/thing/set_control_mode`는 develop `SetControlMode.srv`를 그대로 사용하고 FR-31·34의 획득·갱신·해제 규칙을 구현한다. 응답 `reason`의 스키마는 자유 문자열이며 표준 문자열은 develop에 없다. MVP 구현은 `accepted`, `invalid_mode`, `owner_conflict`, `safety_not_ready`, `recording_active`, `motion_active` ,`stop_barrier_pending`, `stop_barrier_timeout`이다.

`MODE_DISABLED, OWNER_NONE` 응답은 Guard STOP latch의 선형화 경계다. Command Manager는 service callback과 `/thing/control/stop_barrier_ack` callback을 서로 다른 callback group의 2-thread executor에서 실행하되 mode·owner 중재는 기존 단일 lock으로 직렬화한다. Guard ACK 전에는 성공 응답할 수 없고 ACK timeout 뒤 active mode 재획득을 거부한다.

#### FR-38. 사전 정의 자세 서비스

**우선순위: Must**

`/thing/execute_gesture`는 develop `ExecuteGesture.srv`를 그대로 사용한다.

- Must canonical gesture: `open`, `fist`, `pinch`, `cylindrical_grasp`
- `home|paper→open`, `rock→fist` alias는 중복 7축 값을 만들지 않는다.
- active mode=MANUAL, 유효 WEB owner, `SafetyState=READY|RUN`, 다른 일반 동작 없음일 때만 수락하고 `speed_limit`을 검증한다. READY에서 첫 유효 gesture 명령이 RUN 전이를 일으킨다.
- 서비스 성공은 목표 도달이 아니라 실행 수락을 뜻한다.
- 동작·초기 유지시간 종료, 실행 중 새 요청 거부와 STOP·lease 만료·안전 전이에 의한 취소는 FR-22를 따른다.

#### FR-39. 연속 동작 액션

**우선순위: Could — 2주 Must 범위 밖**

`/thing/execute_sequence`는 develop `ExecuteSequence.action`을 그대로 사용한다. 구현 시 `countdown`, `scissors_rock_paper`만 지원하고 YAML 단계·유지시간을 사용한다. Action 취소, STOP, owner 상실과 안전 전이는 즉시 선점한다.

#### FR-40. Logger 녹화 서비스

**우선순위: Must**

`/thing/start_recording`, `/thing/stop_recording`, `/thing/set_mimic_result`는 develop 서비스 스키마를 그대로 사용해 FR-18을 구현한다.

- Logger가 `uint64` Session ID와 rosbag2를 전담하고 웹은 서비스만 호출한다.
- 별도의 로컬 SQLite·상태 파일은 만들지 않고 활성 세션과 판정 대기는 실행 중 메모리와 RecordingState로 관리한다.
- rosbag2 시작 실패 시 StartRecording을 실패 처리한다.
- StopRecording의 `bag_path`와 RecordingState의 경로는 로컬 원본만 가리킨다.
- SetMimicResult가 수락된 정상 세션만 같은  **thing_logger(Jetson)**의 Logger 측 exporter에 전달한다.
- exporter가 rosbag2를 읽어 완료된 임시 네 파일을 만들며 격리된 uploader는 rosbag2를 직접 읽지 않는다.

#### develop에 없는 항목과 MVP 처리

아래 항목은 기준 커밋에 **없다**.

- 전용 STOP 인터페이스 → 기존 SetControlMode의 DISABLED/NONE으로 처리
- heartbeat/lease·lease ID → 같은 mode·owner SetControlMode 주기 재호출로 처리
- 커스텀 Safety Reset 타입 → 추가하지 않음. 프로젝트 런타임 서비스 `/thing/reset_safety`는 표준 `std_srvs/srv/Trigger`로 계약 확정, `thing_control`의 실제 서버 구현은 후속 작업
- SAFE 전용 command 토픽 → Raspberry Pi 내부 safety/hardware override로 처리
- fault code 표·speed_limit 의미·reason 표준·통신 오류 임계값 → FR-41 YAML과 `docs/interfaces.md`에 프로젝트 규칙으로 추가
- command_manager·safety_manager·thing_hardware·Logger 사이 내부 상태 전파 → 개발 중 구체 reason 값·호출 순서·구독 책임을 확정한다. 기존 공개 ROS 2 스키마와 Safety Reset 계약은 유지하고 안전 통합 시험 전에 `docs/interfaces.md`에 동결한다.
- EC2 upload 상태 필드 → ROS 메시지에 추가하지 않고 uploader 진단으로 처리

따라서 `thing_interfaces`는 `SafetyState.RESET=7`과 `MotorState.torque_enabled` 두 additive delta만 허용하고 7 msg·5 srv·1 action 구성을 유지한다. `/thing/reset_safety` 계약, `thing_control`의 `std_srvs` dependency와 프로젝트 의미 규칙은 V7 구현·문서로 함께 검증한다.

#### FR-41. ROS 2 설정 파일

**우선순위: Must**

YAML에서 motor ID·축 매핑·위치·속도·전류·온도 제한, 안전 자세, FR-11 timeout, FR-14 통신 fault와 gesture 목표를 관리한다. fault code 표·speed_limit 의미·reason 문자열은 `docs/interfaces.md`에서 관리하고 토큰은 YAML·Git에 두지 않는다. Sequence 설정은 Could다.

카메라·MediaPipe·hand target·MJPEG 설정을 YAML 관리 대상

#### XL330-M288-T 실제 모터 환경 기준

운영 및 통합 제어의 단일 기준: thing_ws/src/thing_bringup/config/motors.yaml

단일 모터 검증 및 캘리브레이션 전용: thing_ws/src/thing_hardware/config/*_flex.yaml

모터 설정의 단일 기준은
`thing_ws/src/thing_bringup/config/motors.yaml`로 한다. standalone 검증
스크립트의 기본값과 ROS 2 운영 설정이 다를 경우 `motors.yaml`을 우선하며,
측정되지 않은 값을 추정해서 채우지 않는다.

`motors.yaml` 파일:

```yaml
motor_driver_node:
  ros__parameters:
    baud_rate: 57600
    protocol_version: 2.0
    read_rate_hz: 20.0
    write_rate_hz: 50.0
    hardware_command_watchdog_ms: 500
    bus_names: [BUS_A, BUS_B, BUS_C]
		bus_devices: [...]
		motor_ids: [1, 3, 4, 7]
		actuator_names: [ring_flex, middle_flex, index_flex, little_flex]
		bus_indices: [0, 0, 1, 2]
		home_positions: [110, 750, 1740, 700]
		closed_positions: [2700, 3050, 4300, 3800]
```

공통 설정:

| 항목 | 설정값 |
| --- | --- |
| 모델 | DYNAMIXEL XL330-M288-T |
| 모터 수 | 활성 7개 |
| Protocol | 2.0 |
| Baud rate | 57,600bps |
| Operating Mode | 5(Current-based Position Control Mode) |
| Encoder resolution | 4,096 raw/rev |
| 상태 읽기 주기 | 20Hz |
| 목표 쓰기 주기 | 50Hz |
| Profile Velocity | 200 raw |
| Profile Acceleration | 50 raw |
| Current Limit | 1,470mA |
| 이동 Goal Current | 최대 500mA |
| Goal PWM | 최대 885 |

물리 버스 구성:

| Bus | U2D2 식별자 | Motor ID |
| --- | --- | --- |
| BUS_A | FTBIN51S | 1, 2, 3 |
| BUS_B | FTBIHT0L | 4, 5, 6 |
| BUS_C | FTBIHTHG | 7 |

축별 실물 보정값:

| Motor ID | 축 | 펼침 raw | 파지 raw | 상태 |
| --- | --- | --- | --- | --- |
| 1 | `ring_flex` | 110 | 2700 | 확인 |
| 2 | `thumb_flex` | TBD | TBD | 연동축 캘리브레이션 진행 중 |
| 3 | `middle_flex` | 750 | 3050 | 확인 |
| 4 | `index_flex` | 1740 | 4300 | 확인 |
| 5 | `thumb_abduction` | TBD | TBD | 연동축 캘리브레이션 진행 중 |
| 6 | `thumb_opposition` | TBD | TBD | 연동축 캘리브레이션 진행 중 |
| 7 | `little_flex` | 700 | 3800 | 확인 |

위치 도달 허용 오차: +-30 pulse

ID 2·5·6의 논리축 매핑은 확정됐다.
다만 세 축이 기구적으로 서로 영향을 주므로 home/closed 위치와
연동 보정 모델이 확정되기 전에는 전체 7축 운영 INIT을 통과시키지 않는다.

현재 1,470mA와 PWM 885는 감독 상태의 짧은 실물 동작 시험에 사용하는
이동 상한이다. 연속 유지 전류로 간주하지 않는다. 유지 전류, 과전류
trip, 과온 warning/trip 및 Bus Watchdog 값은 모니터링 구현과 부하 시험을
통과하기 전까지 설정 파일에서 `null`로 유지한다. `null` 또는 제조사
범위를 벗어난 보호 설정이 있으면 운영 INIT은 실패해야 한다.

standalone 웨이브 검증 기준:

- 손가락 순서: 검지(ID 4) → 중지(ID 3) → 약지(ID 1) → 소지(ID 7)
- 굽힘 0.8초, 유지 0.5초, 펴짐 0.8초
- 인접 손가락 시작 간격 0.4초
- 정방향 후 역방향으로 1회 복귀

standalone 파지 검증 기준:

- ID 4·3·1·7을 1.5초 동안 동시에 굽힌다.
- 0.05초 후 엄지 ID 2를 3877에서 5117로 1초 동안 이동한다.
- 2초 유지 후 엄지를 먼저 3877로 복귀시킨다.
- 나머지 네 손가락을 펼침 위치로 복귀시키고 전체 토크를 끈다.

엄지축 보정 완료 전 standalone 파지 검증에서 ID 2 제어는 제외한다.
엄지 포함 시험은 Mode 5의 위치 범위와 Torque 재활성화 후 기준점을
실물 검증한 뒤 별도 프로파일로 추가한다.

위 웨이브·파지 값은 현재 실물 검증 프로파일이며 ROS 2 운영 인터페이스
상수가 아니다. Gesture executor 통합 전까지 실행 명령과 값은
`tools/dynamixel/rpi/MOTION_COMMANDS.md`에서 관리한다.

#### FR-42. Bringup Launch

**우선순위: Must**

장치 내부 ROS 노드는 launch로 시작하되 최상위 운영 시작은 Jetson `docker run` 스크립트와 Raspberry Pi `docker compose up -d`를 따른다. 시작 실패는 이전 명령 자동 재생 없이 INIT 또는 명확한 실패 상태로 남아야 한다.

Jetson launch에 **6개** 노드 포함(camera·mediapipe·hand_target·mjpeg·web_bridge·**logger**), 격리 uploader는 launch 밖 별도 프로세스"

#### FR-43. 패키지 빌드 및 검증

**우선순위: Must**

`colcon build`, develop 스키마 직렬화, command guard, mode·owner 충돌, timeout·lease, 안전 전이, Recording 서비스 시험이 통과해야 한다. CI 증거 자동 첨부와 이미지 태그 자동화는 Should다.

각 노드와 토픽 연결 시험 추가

#### FR-44. Nominal 관절 자세 시각화

**우선순위: Could — 2주 범위 밖**

URDF·RViz nominal 자세 시각화는 실제 관절각 측정으로 해석하지 않는다.

#### FR-45. 자세 추론 연구

**우선순위: Could — 2주 범위 밖**

motor encoder와 향후 센서 데이터 기반 관절 자세 추론은 연구 항목이며 MVP 완료 조건이 아니다.

---

### 3.9 EC2 기반 데이터 포털

#### 확정된 MVP 데이터 계약

- 공개 접근: 로그인 없는 READY 데이터 GET
- 업로드: 단일 로봇 Bearer Token + HTTPS
- 로봇 로컬 저장: rosbag2 원본 + 업로드 시점의 임시 네 파일. 별도 애플리케이션 DB·영구 spool 없음
- EC2 저장: SQLite와 `EC2_DATA_DIR=/var/lib/thing-data`
- 공개 파일: metadata JSON, HandCommand CSV, MotorStatus CSV, LandMark JSON 정확히 네 개
- 제외: landmark, ControlState·SafetyState 이력, 영상, rosbag2
- 시간: UTC, `schema_version=1`, `data_version=1`
- 다중 data version, 파일 교체, S3는 이번 2주 범위 밖

#### FR-46. 완료 세션 직접 EC2 전송

**우선순위: Must**

SUCCESS·FAILURE 판정 직후 **Jetson thing_logger**의 exporter와 격리된 uploader는 6.5절에 따라 네 파일을 생성·검증·비동기 업로드해야 한다.

- 임시 경로: `/var/lib/thing-robot-data/tmp-upload/{session_id}/`
- exporter가 rosbag2를 읽고 네 파일을 `.part`로 작성한 뒤 fsync·schema·행 수·SHA-256을 검증하여 같은 임시 디렉터리 안에서 최종 파일명으로 원자적 rename한다.
- uploader는 rosbag2 mount를 갖지 않는다. exporter는 완료된 네 파일 경로와 `content_digest`만 `/run/thing-uploader/uploader.sock`의 private Unix socket으로 전달하고, uploader는 임시 디렉터리를 읽기 전용으로 사용한다.
- 실행 중 상태는 메모리에서 `EXPORTING→UPLOADING→UPLOADED|FAILED`로 관리하고 uploader 진단 로그에 결과를 남긴다. 이를 위한 로컬 DB나 영구 queue는 만들지 않는다.
- 신규 `(robot_id, session_id)`와 `content_digest`는 201, 기존 key의 같은 `content_digest` 재전송은 200, 같은 key의 다른 `content_digest`는 409이며 덮어쓰지 않는다.
- exporter는 private Unix socket을 통해 완료된 canonical 네 파일을 uploader에 인계하고 ACK를 확인한다. 실제 HTTPS 업로드와 EC2 응답 검증은 uploader가 담당한다. handoff 시도가 종료되면 exporter의 임시 네 파일은 정리하며, 완료된 원본 rosbag2는 보존한다. MVP에서는 수동 재업로드와 자동 복구 업로드를 제공하지 않는다.
- 업로드 실패 시 임시 네 파일을 정리하고 오류를 기록한다.
- 인터넷 단절 장기 보관, 지수 backoff, 재부팅 후 자동 upload 복구는 2주 MVP 범위에서 제외한다. 업로드 실패가 로봇 제어·안전을 중단시키지 않아야 한다.

#### FR-47. 공개 세션 목록 및 상세 조회

**우선순위: Must**

READY 세션의 Session ID, UTC 시작·종료·업로드 시각, 결과, 기간, 세 데이터 파일의 행 수와 네 파일의 크기를 로그인 없이 조회해야 한다.

- 기본 정렬은 `started_at DESC, session_id DESC`, 기본 20개·최대 100개다.
- 존재하지 않는 세션은 404, STAGING·FAILED는 공개하지 않는다.
- 정확한 Session ID 검색은 Must다. 날짜·결과 필터와 cursor pagination은 Should다.

#### FR-48. 로봇 데이터 표시

**우선순위: Must**

상세 화면은 7논리축 HandCommand와 모터별 목표·현재 위치, motor-axis rad, 속도, 전류, 전압, 온도와 통신 여부를 기본 표 또는 그래프로 표시해야 한다.

- 단위·UTC·결측·통신 실패를 구분하고 모터축 각도가 실제 관절각이 아님을 표시한다.
- 한 개의 기본 시계열 차트와 표는 Must다. 다축 고급 차트·구간 조회·서버 다운샘플링은 Should다.

#### FR-49. 데이터 다운로드

**우선순위: Must**

세션마다 canonical 이름의 metadata JSON 1개, HandCommand CSV 1개, MotorStatus CSV 1개, LandMark JSON 1개를 로그인 없는 GET으로 다운로드해야 한다. 파일 누락·hash 불일치는 정상 다운로드로 제공하지 않는다. 크기 사전표시와 공개 checksum 표시는 Should·Could다.

#### FR-50. 조회 전용 보안 경계

**우선순위: Must**

EC2에는 조회·다운로드 GET과 장치 인증 upload POST만 둔다. 로봇 명령, mode·기록·Safety Reset, callback·socket, ROS 2·rclpy·DDS와 내부 Web Bridge를 설치·노출하지 않는다.

#### FR-51. 업로드 인증과 입력 검증

**우선순위: Must**

- `Authorization: Bearer <device-token>`과 TLS 인증서 검증을 강제하고 누락·오류는 401이다.
- 원문 token은 **Jetson** `/etc/thing/uploader.env`의 0600 파일에만 두고, EC2에는 비교용 token hash를 0600 systemd EnvironmentFile로 주입한다. 어느 값도 Git·이미지·Compose·로그에 넣지 않는다.
- 서버가 파일명·경로를 생성하고 part, content type, schema, header, 행 수, 유한값, 크기, hash와 robot ID를 검증한다.
- part 상한은 metadata 256KiB, HandCommand 20MiB, MotorStatus 60MiB, 네 파일 합계 80.25MiB다. Django request 85MiB, Nginx body 90MiB로 고정한다.
- 기록 상한은 기본 60분이며 초과 전에 정상 종료·판정 절차로 넘어간다.

#### FR-52. EC2 네이티브 배포와 상태 확인

**우선순위: Must**

EC2에는 Docker·Compose를 사용하지 않는다.

- Nginx: `EC2/frontend` React 정적 파일·HTTPS·reverse proxy
- Gunicorn+Django: `EC2/backend`, Python venv와 systemd
- SQLite·파일: `/var/lib/thing-data`, 서비스 재시작·EC2 재부팅 후 유지
- 공개 인바운드: 443만. 관리용 22는 팀 고정 IP로 제한하며 DDS port는 열지 않는다.
- `/health`는 Django, SQLite 접근과 데이터 디렉터리 쓰기 가능 시 200을 반환하되 경로·비밀정보를 노출하지 않는다.
- React build, Django test·deploy check, native 배포 절차와 재부팅 복구 시험은 Must다. GitLab CI 수동 운영 배포와 자동 rollback은 Should다.

### 3.10 배포 및 실행 환경

#### FR-53. Jetson·Raspberry Pi Docker 실행

**우선순위: Must**

Docker 적용 대상은 Jetson과 Raspberry Pi로 제한하고 Compose는 Raspberry Pi에서만 사용한다.

- Laptop: Docker 없이 `web/*~~internal-control/~~*frontend`의 Vite+React를 native로 실행하고 Jetson의 Web Bridge·MJPEG에 내부망으로 연결한다.
- Jetson: 버전 관리된 Dockerfile과 `docker run` 스크립트로 vision·MJPEG·Web Bridge**·logger·격리 uploader** 컨테이너를 실행한다. **uploader에는 Unix socket 디렉터리(rw)와 임시 네 파일 디렉터리(ro) bind mount를 적용한다.** Compose 금지.
- Raspberry Pi: 버전 관리된 Docker Compose로 **thing-control을** docker compose up -d로 시작한다.
- `thing-control`은 manager·guard·safety·DYNAMIXEL·Logger와 Logger 측 exporter를 포함한다. rosbag2 원본은 이 서비스만 읽는다.
- `thing-data-uploader`는 `/run/thing-uploader/uploader.sock`의 private Unix socket으로 전달된 완료 job만 받고 임시 네 파일 디렉터리를 읽기 전용으로 mount한다. rosbag2·모터 장치·제어 publish 권한을 갖지 않고 외부 HTTPS만 사용한다.
- 카메라는 Jetson 컨테이너에만, U2D2는 Raspberry Pi control 서비스에만 연결한다.
- rosbag2·로그는 Raspberry Pi의 제한된 영속 bind mount로 관리하고 임시 업로드 디렉터리는 용량을 제한한다. 별도 SQLite·`session_state.json`·영구 spool 볼륨은 만들지 않는다.
- ROS_DOMAIN_ID, 장치·저장 경로와 EC2 URL은 외부 설정으로, 토큰은 0600 env 파일로 주입한다.
- restart 정책 뒤 항상 INIT에서 시작하며 이전 명령·mode·owner·녹화·upload job을 재생하지 않는다.
- 기능별 추가 컨테이너 분리와 CI 이미지 자동 태그는 Should다.
- Jetson 컨테이너의 노드 목록, 카메라 장치 mount, MJPEG HTTP port 명시

EC2와 개발 Laptop은 FR-53 Docker 범위에 포함하지 않는다. 구현 일정과 Jira 작업 분해는 요구사항 명세가 아니라 Jira/WBS에서 관리한다.

---

## 4. 프로세스 흐름 및 시스템 아키텍처

### 4.1 장치 배치

```
Laptop — native Node.js
└─ web/*~~internal-control/~~*frontend: Vite · React
              │ WebSocket · MJPEG / 내부 Wi-Fi
              ▼
Jetson Orin Nano — Docker run
└─ camera_node, mediapipe_node, hand_target_node, mjpeg_streamer, web_bridge_node, logger(exporter)
              │ ROS 2 DDS / 내부 Wi-Fi
              ▼
Raspberry Pi 5 — Docker Compose
├─ command_manager · command_guard · safety_manager · motor_driver_node
└─ thing-data-uploader: completed four files · HTTPS upload
              │ U2D2 / 별도 모터 전원
              ▼
7 × DYNAMIXEL XL330-M288-T → 텐던 로봇 손

Raspberry Pi uploader ── Bearer Token HTTPS ──▶ AWS EC2
AWS EC2 — native systemd
└─ EC2: Nginx · React · Gunicorn · Django · SQLite · EC2_DATA_DIR
```

logger(exporter)

내부 제어 React는 Laptop에서, Web Bridge·MJPEG는 Jetson에서 실행한다. Docker는 Jetson·Raspberry Pi에만, Compose는 Raspberry Pi에만 적용한다. EC2에는 ROS 2와 Docker를 설치하지 않는다.

### 4.2 모방 명령 흐름

```
카메라 → HandLandmarks → 7논리축 HandCommand
→ /thing/command/mimic → command_manager
→ /thing/command/selected → command_guard
→ /thing/command → DYNAMIXEL → 로봇 손

**- vision 세부 로직**

USB RGB Camera
└─ thing_vision/camera_node
   └─ publish /thing/image_raw
      ├─ thing_vision/mediapipe_node
      │  └─ publish /thing/landmarks
      │     ├─ thing_vision/hand_target_node
      │     │  └─ publish /thing/command/mimic
      │     │     └─ thing_control/command_manager
      │     ├─ thing_web_bridge/mjpeg_streamer
      │     ├─ thing_web_bridge/web_bridge_node
      │     └─ rosbag2 recorder
      └─ thing_web_bridge/mjpeg_streamer
         └─ MJPEG HTTP Stream → Laptop React 웹
```

mode·owner는 HandCommand가 아니라 SetControlMode와 ControlState로 관리한다.

### 4.3 내부망 웹 흐름

Laptop에서 실행하는 React frontend는 Jetson의 `/ws/robot-state` WebSocket과 MJPEG를 사용한다. MJPEG는 관제 전용이고 영상은 저장하지 않는다. Jetson Web Bridge는 정의된 mode·gesture·recording 요청만 ROS 2로 변환하며 모터 장치에 직접 접근하지 않는다. 서버→클라이언트 상태 snapshot은 6.4절의 top-level JSON 계약을 따른다.

`image_raw + landmarks → mjpeg_streamer → HTTP MJPEG → 웹` 추가

### 4.4 상태 피드백 흐름

`/thing/motor_status`, `/thing/control_state`, `/thing/safety_state`, `/thing/recording_state`, `/thing/diagnostics, /thing/landmarks`를 Web Bridge·Logger·개발 도구가 소비한다. `/joint_states`는 develop 동결 계약에 없으므로 Must 경로가 아니다.

### 4.5 기록 흐름

```
StartRecording → uint64 Session ID → rosbag2
StopRecording → 메모리의 result pending → SetMimicResult
→ thing-control Logger 측 exporter가 임시 네 파일 생성·검증
→ private Unix socket으로 완료 파일 job 전달
→ 격리된 uploader가 즉시 비동기 EC2 upload
```

활성 세션과 판정 대기는 Logger 실행 중 메모리와 RecordingState로만 관리한다. 별도 로컬 DB·상태 파일은 없으며 프로세스 재시작 뒤 이전 세션을 자동 재개·업로드하지 않는다.

### 4.6 안전·충돌 우선순위

```
물리 ESTOP > FAULT > SAFE > HOLD
> STOP·lease 만료 > active mode의 일반 명령
```

안전 전이와 STOP은 Gesture·Action·일반 명령을 취소한다. 동시에 온 mode 획득은 한 요청만 수락하며 다른 owner는 거부한다.

### 4.7 직접 EC2 업로드 흐름

```
판정 완료 rosbag2
→ thing-logger exporter: metadata.json + hand_command.csv + motor_status.csv + LandMark JSON 임시 생성
→ schema·행 수·SHA-256·content_digest 검증
→ private Unix socket으로 완료된 네 파일 job 전달
→ 격리된 uploader가 Bearer Token HTTPS POST
→ EC2 STAGING 검증
→ 파일 atomic rename + EC2 SQLite READY transaction
→ 로그인 없는 GET 조회·다운로드
→ 응답 content_digest 일치 확인 후 로봇 임시 네 파일 삭제
```

영구 로컬 spool과 자동 장애 복구는 사용하지 않는다. 업로드 실패는 진단 로그에 남기고 임시 네 파일을 정리하며 완료된 원본 rosbag2는 보존한다. MVP에서는 수동 재업로드 CLI를 제공하지 않는다.

### 4.8 EC2 네이티브 배치

Nginx는 `EC2/frontend`의 React 정적 파일과 HTTPS를 제공하고 `EC2/backend`의 Gunicorn·Django는 systemd로 실행한다. SQLite와 네 파일은 `/var/lib/thing-data`에 영속한다. 공개 443 외의 DDS·제어 포트는 열지 않고, 관리 SSH는 팀 고정 IP만 허용한다.

### 4.9 두 웹사이트 역할 및 저장소 경계

```
web/
│  *~~internal-control/~~*
├─  frontend/        # Laptop native Vite + React
EC2
├─ frontend/        # EC2 Nginx가 제공하는 React build
└─ backend/         # EC2 Django REST API

thing_ws/src/thing_web_bridge/  # Jetson ROS 2 ↔ WebSocket Bridge
```

- 내부망 웹: Laptop 브라우저가 Jetson MJPEG와 `/ws/robot-state` WebSocket을 통해 ROS 2의 실시간 영상·상태를 받고 MIMIC·MANUAL·기록 요청을 보낸다. rosbag2와 DB는 실시간 통신 경로가 아니다.
- 로봇 uploader: 판정 완료 네 파일을 Bearer Token HTTPS POST로 EC2 Django API에 전송한다.
- EC2 포털: 브라우저가 HTTPS 공개 GET으로 Django API를 호출하고 EC2 SQLite·파일 디렉터리에 저장된 READY 세션을 조회·다운로드한다.
- 공통 금지: EC2에서 로봇으로 향하는 명령·callback·DDS 경로
- `thing_vision`과 `thing_web_bridge`의 노드별 책임

---

## 5. 비기능 요구사항

### 5.1 성능·기구 품질

#### NFR-01. 영상 처리 성능

**우선순위: Must**

검출은 평균 20FPS 이상, 유효 MIMIC HandCommand는 20Hz 이상이어야 한다.

camera 30FPS, MediaPipe 평균 20FPS, HandCommand 20Hz를 분리 측정

#### NFR-02. 응답 지연

**우선순위: Must**

카메라 frame 시각부터 최초 MotorStatus 반응까지 30회 P95 300ms 이하여야 한다.

카메라 `header.stamp`부터 MotorStatus까지 P95 300ms 측정

#### NFR-03. 내구성

**우선순위: Must**

텐던 이탈·부품 파손 없이 10분 연속 시연해야 한다.

#### NFR-04. 파지 성공률

**우선순위: Must**

원통과 집기 물체를 각각 10회 시험해 7회 이상 3초 유지해야 한다.

### 5.2 신뢰성·안전

#### NFR-05. 명령 유효성

**우선순위: Must**

FR-32의 source·stamp·sequence·유한값·범위 검사를 통과하지 못한 명령은 모터에 전달하지 않는다.

#### NFR-06. 고장 격리

**우선순위: Must**

모터·Logger·uploader·웹 하나의 장애가 전체 프로세스와 물리 E-Stop을 무력화하지 않아야 하며 원인을 식별할 수 있어야 한다.

MJPEG/Web 장애가 MediaPipe·MIMIC 명령을 막지 않아야 함

#### NFR-07. 기구 안전

**우선순위: Must**

스프링 과신장, 텐던 이탈, 손가락 물리 범위 초과와 검증되지 않은 토크를 구조·설정으로 제한한다.

### 5.3 사용성·운영

#### NFR-08. 실행 편의성

**우선순위: Must**

Laptop 내부 제어 웹은 문서화된 Vite 실행 명령, Jetson은 `docker run` 스크립트, Raspberry Pi는 `docker compose up -d`, EC2는 systemd 절차로 시작·상태 확인·중지할 수 있어야 한다.

#### NFR-09. 상태 확인

**우선순위: Must**

Laptop 내부망 웹에서 손 검출, mode·owner, 연결, SafetyState, RecordingState를 확인하고 상세 원인은 diagnostics·로그에서 확인한다.

각 Vision 노드의 실행·연결 상태 확인

### 5.4 유지보수·확장

#### NFR-10. 모듈 분리

**우선순위: Should**

vision, 제어·안전, hardware, Logger, uploader, 웹과 EC2를 책임별로 분리한다. Must 통합을 지연시키는 추가 package 리팩터링은 이월한다.

캡처·검출·7축 계산·영상 송출 책임 분리

#### NFR-11. 설정 분리

**우선순위: Must**

FR-41의 motor·gesture·timeout·fault 설정은 코드와 분리하고 유효성 검사·기본값·단위를 문서화한다.

#### NFR-12. 향후 센서 확장

**우선순위: Could — 2주 범위 밖**

관절각·스프링·촉각·힘 센서 확장은 기존 MVP 스키마를 임의 변경하지 않고 별도 버전에서 검토한다.

### 5.5 내부망 웹

#### NFR-13. 화면 응답

**우선순위: Should**

버튼 반영 200ms, 손·7축 10Hz, 모터·상태 5Hz를 목표로 하며 UI 갱신이 ROS 20Hz 명령을 막지 않는다.

#### NFR-14. 영상 표시

**우선순위: Should**

MJPEG 평균 15FPS·지연 500ms 이하를 목표로 하고 영상 지연은 제어 경로와 분리한다.
서로 다른 프레임의 image와 landmark를 합성하지 않도록 규칙 

#### NFR-15. 제어 안정성

**우선순위: Must**

중복·stale 요청을 실행하지 않고 새로고침·종료·연결 단절 시 lease가 만료되어 안전 전이한다. 재연결은 이전 명령을 재생하지 않는다.

#### NFR-16. 웹 장애 독립성

**우선순위: Must**

웹·MJPEG·Web Bridge 장애 중에도 Raspberry Pi의 범위·속도·timeout·E-Stop 판단은 계속 동작한다.

#### NFR-17. 사용성

**우선순위: Should**

MIMIC·MANUAL, 현재 mode, STOP, 편 손·주먹·파지·집기와 정상·경고·오류를 구분해 표시한다.

#### NFR-18. 화면 구성

**우선순위: Could**

고정 상태 바, 게이지·그래프, 반응형 상세 패널과 장식성 개선은 Must 화면 뒤 진행한다.

#### NFR-19. 호환성

**우선순위: Could**

데스크톱 Chrome 최신 버전을 Must 검수 기준으로 삼고 추가 브라우저·반응형 범위는 후순위다.

#### NFR-20. 내부망 제어 보안

**우선순위: Must**

제어 웹과 Web Bridge는 내부망에만 두고 임의 ROS topic·motor ID 입력과 외부 인터넷 제어 API를 금지한다.

#### NFR-21. 유지보수성

**우선순위: Should**

UI, WebSocket adapter, 상태 store와 preset을 분리해 웹 변경이 hardware 코드를 직접 바꾸지 않게 한다.

#### NFR-22. 이벤트 로그

**우선순위: Should**

mode, 명령, 기록, 연결, 손 미검출, fault·E-Stop과 결과를 timestamp와 함께 회전 로그로 남긴다. 실패가 제어를 중단시키지 않는다.

#### NFR-23. 복구 가능성

**우선순위: Must**

손 재검출이나 연결 복구 뒤 시스템과 웹은 현재 SafetyState·mode·owner·원인을 다시 조회하고 FR-35의 현재 상태별 절차를 따라야 한다.

- HOLD에서는 연결 복구만으로 RUN에 가지 않는다. 기존 active mode·owner 아래 Guard의 전체 검증을 통과한 activity가 최대 gap 100ms로 300ms 연속일 때만 자동복귀하며, activity는 HOLD 중 motor로 전달하지 않는다.
- SAFE·FAULT·ESTOP에서는 원인 해소와 안정 시간, `/thing/reset_safety`, INIT 진입 이후 새 MotorStatus·E-Stop heartbeat  재검사와 READY 전환을 완료한 뒤 MIMIC mode와 owner를 새로 획득해야 한다.
- 어느 경로에서도 이전 command, Gesture, Sequence(Action) 및 recording을 자동 재개하지 않는다. HOLD 자동복귀도 새 sequence·fresh stamp의 검증 activity만 인정한다.

### 5.6 공통 보안 경계

내부망 제어와 EC2 공개 데이터 포털을 분리한다. 외부 인터넷에는 HTTPS 443의 저장 데이터 GET과 장치 upload POST만 공개하고 로봇 제어 REST·WebSocket·DDS를 제공하지 않는다. 이 절은 FR-28·50·51의 공통 원칙이며 세부 API는 6.5절을 따른다.

### 5.7 EC2 데이터 포털

#### NFR-24. 부하 성능

**우선순위: Could**

READY 100세션 목록·상세 P95 3초와 고급 downsampling 부하 시험은 2주 최소 검수 밖이다. 대표 세션 정상 조회·다운로드는 Must다.

#### NFR-25. 다운로드 무결성

**우선순위: Must**

서버가 저장한 네 파일의 SHA-256과 실제 파일이 일치하고, metadata에 기록된 세 데이터 파일인 HandCommand CSV, MotorStatus CSV, LandMark JSON의 행 수·크기·SHA-256이 실제 파일과 일치하는 READY만 제공해야 한다. 반복 GET은 원본 파일을 변경하지 않아야 한다

#### NFR-26. 업로드 신뢰성

**우선순위: Must**

동일 `(robot_id, session_id)`와 동일 `content_digest`는 중복 없이 200, 같은 key의 다른 `content_digest`는 409다. STAGING 부분 파일은 공개하지 않고 crash 뒤 재조정할 수 있어야 한다.

#### NFR-27. 인증·공개 데이터 보호

**우선순위: Must**

업로드만 Bearer Token으로 인증하고 공개 GET은 로그인 없이 읽기 전용으로 제공한다. 토큰·내부 경로·IP·원시 영상 및 exporter·uploader의 내부 처리 상태는 공개 데이터와 로그에서 제외한다.

#### NFR-28. 제어와 업로드 장애 독립성

**우선순위: Must**

exporter·uploader·EC2 업로드 실패가 ROS 제어·SafetyState·rosbag2를 중단하거나 지연시키지 않아야 하며 실패 원인을 진단 로그에 남겨야 한다. 인터넷 단절 중 영구 보관과 자동 재시도는 2주 MVP 범위에서 제외한다.

#### NFR-29. 저장 공간과 지속성

**우선순위: Must**

로봇은 완료된 rosbag2 원본과 용량이 제한된 임시 export 디렉터리만 사용하며, 별도의 애플리케이션 SQLite·상태 파일·영구 spool을 만들지 않는다. handoff 시도가 종료되면 exporter의 임시 canonical 네 파일을 정리하고, 완료된 rosbag2 원본은 보존한다. EC2 SQLite와 네 파일은 systemd 재시작 및 EC2 재부팅 후에도 유지한다. S3와 자동 공개 삭제는 2주 범위 밖이다.

---

## 6. 외부 인터페이스 요구사항

### 6.1 사용자 인터페이스

- 내부망 웹: MJPEG, 손 검출·7축, mode·owner, 모터·안전·기록 상태, MIMIC·MANUAL·STOP·기록 요청
- EC2 포털: READY 세션 목록·상세·기본 시계열과 네 파일 다운로드

EC2 화면에는 로봇 제어·기록·Safety Reset을 두지 않는다.

영상은 MJPEG, 구조화된 손 정보는 WebSocket으로 수신

### 6.2 하드웨어 인터페이스

- RGB 카메라: Jetson 컨테이너에만 USB 연결
- XL330-M288-T 7개: 고유 motor ID와 같은 baud rate
- U2D2: Raspberry Pi control 서비스에만 연결
- 모터 전원: Raspberry Pi와 분리하고 7개 모터 순간 전류를 감당
- 텐던·스풀·스프링: 미끄러짐·다층 권취·과신장 방지
- E-Stop: 모터 전원 주접점과 절연 GPIO용 NC 보조접점
- USB 카메라는 `camera_node`만 직접 사용
- Raspberry Pi에서 motor_driver_node만 3개의 U2D2 포트를 독점 소유

### 6.3 ROS 2 소프트웨어 인터페이스

단일 기준:

- [GitLab develop/thing_interfaces](https://lab.ssafy.com/s15-webmobile3-sub1/S15P11C103/-/tree/develop/thing_ws/src/thing_interfaces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)
- 검증 커밋 `70dfdab8d555dfbfdd471c5acca4f30a8a8fc3ec`

#### 명령·상태 토픽

- `/thing/landmarks`: `thing_interfaces/msg/HandLandmarks`
- `/thing/command/mimic`: `thing_interfaces/msg/HandCommand`
- `/thing/command/teleop`: `thing_interfaces/msg/HandCommand`
- `/thing/command/manual`: `thing_interfaces/msg/HandCommand`
- `/thing/command/selected`: `thing_interfaces/msg/HandCommand`
- `/thing/command`: `thing_interfaces/msg/HandCommand`
- `/thing/motor_status`: `thing_interfaces/msg/MotorStatus`
- `/thing/control_state`: `thing_interfaces/msg/ControlState`
- `/thing/safety_state`: `thing_interfaces/msg/SafetyState`
- `/thing/recording_state`: `thing_interfaces/msg/RecordingState`
- `/thing/diagnostics`: `diagnostic_msgs/msg/DiagnosticArray`

| 토픽 | 타입 | 발행 노드 | 구독 노드 |
| --- | --- | --- | --- |
| `/thing/image_raw` | `sensor_msgs/msg/Image` | `camera_node` | `mediapipe_node`, `mjpeg_streamer` |
| `/thing/landmarks` | `thing_interfaces/msg/HandLandmarks` | `mediapipe_node` | `hand_target_node`, `mjpeg_streamer`, `web_bridge_node, thing_logger:logger` |
| `/thing/command/mimic` | `thing_interfaces/msg/HandCommand` | `hand_target_node` | `command_manager` |

#### 서비스·액션

- `/thing/set_control_mode`: `thing_interfaces/srv/SetControlMode`
- `/thing/execute_gesture`: `thing_interfaces/srv/ExecuteGesture`
- `/thing/start_recording`: `thing_interfaces/srv/StartRecording`
- `/thing/stop_recording`: `thing_interfaces/srv/StopRecording`
- `/thing/set_mimic_result`: `thing_interfaces/srv/SetMimicResult`
- `/thing/execute_sequence`: `thing_interfaces/action/ExecuteSequence` — Could

#### develop 외 프로젝트 확장

- `/thing/reset_safety`: `std_srvs/srv/Trigger`, Raspberry Pi 내부망 전용
- `/thing/control/stop_requested`: `std_msgs/msg/Empty`, Command Manager → Command Guard
- `/thing/control/stop_barrier_ack`: `std_msgs/msg/Empty`, Command Guard → Command Manager·Safety Manager
- `/thing/command/validation_result`: `std_msgs/msg/Bool`, Command Guard → Safety Manager; 단일 ordered 채널에서 `true`는 HOLD 복구 activity, `false`는 연속 window 초기화이며 motor command가 아님
- 전용 STOP·heartbeat·lease·SAFE command·EC2 upload 상태 인터페이스는 develop에 없다. FR-34의 SetControlMode 재사용과 Raspberry Pi 내부 override로 처리한다.

#### Safety Reset 서비스 계약

서비스 식별과 책임:

- 서비스 이름: `/thing/reset_safety`
- 서비스 타입: `std_srvs/srv/Trigger`
- 서비스 제공 노드: `safety_manager`
- 노드 소속 패키지: `thing_control`
- 구현 위치: `thing_ws/src/thing_control/thing_control/safety_manager.py`
- 실행 위치: Raspberry Pi의 `thing-control` 실행 환경과 프로젝트 내부망
- 외부 노출: EC2·외부망·공개 REST API·공개 WebSocket에 노출하지 않음

`/thing/reset_safety`는 프로젝트의 ROS 2 인터페이스 계약이지만 커스텀 `thing_interfaces` 타입은 아니다. 표준 Trigger 타입을 사용하므로 `thing_interfaces/srv/ResetSafety.srv`를 추가하지 않고 `thing_interfaces/CMakeLists.txt`의 인터페이스 생성 목록도 변경하지 않는다. `thing_interfaces`는 메시지 7종·서비스 5종·액션 1종을 그대로 유지한다.

실제 서비스 서버는 `thing_control` 패키지의 `safety_manager`가 담당한다. `thing_control/package.xml`은 표준 Trigger 타입을 사용하기 위한 `std_srvs` 실행 의존성을 갖는다. Safety Manager 상태 머신과 mock 기반 통합 시험은 구현됐으나 실제 E-Stop GPIO·MotorStatus publisher·torque readback 통합은 hardware 담당 구현 후 별도 실물 검증해야 한다.

Trigger 의미:

- 요청 필드는 없다.
- 응답 `success`는 Reset 요청의 수락 여부다.
- 응답 `message`는 수락 또는 거부 이유다.
- 호출 의미는 현재 SAFE·FAULT·ESTOP 원인과 안정시간을 다시 검사하고, 조건을 만족하면 INIT 전체 재검사를 시작해 달라는 요청이다.
- `success=true`는 INIT 검사 통과나 READY 도달을 보장하지 않는다. 최종 진행 상태는 `/thing/safety_state`로 확인한다.
- 수락 직전 cache는 INIT 통과 증거가 아니다. INIT 진입 이후 새 MotorStatus와 새 E-Stop heartbeat를 모두 받아야 한다.

허용 상태와 안정시간:

- SAFE·FAULT·ESTOP에서만 복구 요청으로 사용한다.
- HOLD에서는 Safety Reset은 거부하지만 명시적 STOP은 허용한다. 기존 owner의 동일 mode lease 갱신과 Guard 검증 recovery-only activity로 300ms 연속 시 RUN 복귀할 수 있으며, STOP을 선택하면 Guard ACK 뒤 RESET으로 간다. 어느 경로도 성립하지 않으면 마지막 hardware-forwarded 명령 기준 총 1000ms에 SAFE로 상승한다.
- SAFE·FAULT 원인은 해소 뒤 `fault_clear_stable_ms=1000`을 만족해야 한다.
- E-Stop은 물리 해제 뒤 `estop_release_stable_ms=500`을 만족해야 한다.
- 원인이나 안정시간 조건을 만족하지 않으면 `success=false`와 거부 이유를 반환하고 현재 안전 상태를 유지한다.

Reset이 수행하지 않는 동작:

- 물리적 E-Stop 해제
- 모터 토크 즉시 활성화
- 이전 mode 또는 owner 복원
- 이전 명령·Gesture·Sequence·queue 재실행
- 이전 녹화 자동 재개
- 즉시 READY 또는 RUN 전환

Reset 요청이 수락되면  reset 직전 cache를 폐기하고 INIT 전체 재검사를 시작한다. INIT 진입 이후 새 MotorStatus·E-Stop heartbeat와 설정·torque-off 검사를 통과하면 토크 OFF·mode=`DISABLED`·owner=`NONE`인 READY까지만 전환한다. RUN으로 전환하려면 새로운 mode·owner 획득과 활성화 이후의 새로운 유효 명령이 필요하다.

현재 구현 상태:

- 서비스 이름·타입 결정: 완료
- 담당 패키지·노드 결정: 완료
- 커스텀 `ResetSafety.srv`를 만들지 않는 결정: 완료
- 요구사항 명세서 V6.2 반영: 완료
- GitLab `docs/interfaces.md`와 `thing_control` dependency 반영: 진행 중
- `safety_manager` 서비스 서버 구현: 후속 작업
- 안정시간 및 상태 전이 구현: 후속 작업
- E-Stop GPIO와 모터 상태 연동: 후속 작업
- 통합 테스트: 후속 작업

따라서 MVP에서 사용할 Safety Reset 인터페이스 계약은 확정됐지만 실제 `/thing/reset_safety` 서버와 전체 안전 기능은 아직 구현 완료 상태가 아니다.

#### QoS

- develop 확정: landmarks sensor data/Best Effort, 최종 command Reliable depth 1, SafetyState·RecordingState Reliable Transient Local, diagnostics 1Hz 이상
- MVP 기본값: 나머지 command Reliable depth 1, MotorStatus Reliable depth 5, ControlState Reliable Transient Local
- 미확정 QoS 튜닝값은 GitLab 확정값으로 오인하지 않도록 `docs/interfaces.md`에 프로젝트 결정으로 기록한다.

#### 내부망 WebSocket

요청은 `request_id`, `type`, `timestamp`, `payload`, 응답은 같은 `request_id`, `accepted`, `reason`을 포함한다. type별 payload는 ROS 2 필드명·상수를 재사용하고 별도 인터페이스 문서에서 동결한다. WebSocket은 임의 topic·motor ID를 받지 않는다.

#### motor_driver_node 인터페이스

| 인터페이스 | 방향 | 역할 |
| --- | --- | --- |
| `/thing/command` | 구독 | Guard가 검증한 최신 목표 |
| `/thing/safety_state` | 구독 | INIT/READY/RUN/HOLD/SAFE/FAULT/ESTOP/RESET 처리 |
| `/thing/motor_status` | 발행 | 모터별 실측 상태와 통신 상태 |
| `/thing/diagnostics` | 발행 | 버스·모터 오류 |
| U2D2 3개 | 독점 접근 | Sync Write와 Sync Read |

### 6.4 통신 인터페이스

- Jetson–Raspberry Pi: 내부 Wi-Fi의 ROS 2 Humble DDS, 같은 ROS_DOMAIN_ID
- 내부망 웹: Laptop 브라우저 ↔ Jetson MJPEG·Web Bridge WebSocket ↔ ROS 2. 실시간 영상·상태·제어 요청 경로이며 rosbag2나 DB를 조회하지 않음
- 제어: manager가 입력 하나를 선택하고 guard만 최종 command 발행
- 기록: 로봇 로컬 rosbag2만 사용하고 웹은 기록 서비스를 호출함
- 업로드: Raspberry Pi uploader가 완료된 네 파일만 Bearer Token outbound HTTPS POST로 Django API에 전송함
- EC2 포털: 사용자 브라우저가 HTTPS 공개 GET으로 Django API를 호출하고 EC2 SQLite와 파일 디렉터리의 READY 데이터만 조회·다운로드함
- EC2: ROS 2 DDS에 참여하지 않고 로봇으로 향하는 연결을 만들지 않음
- 로봇은 EC2 SQLite 파일에 직접 접속하지 않고 HTTPS upload API만 호출하며, Django가 검증 후 EC2 SQLite와 파일 디렉터리를 갱신함

#### 내부망 WebSocket 상태 snapshot v1

Jetson Web Bridge의 서버→클라이언트 endpoint는 `/ws/robot-state`로 고정한다. Laptop frontend는 `WS_URL` 설정으로 내부망 주소를 주입한다. 메시지는 UTF-8 JSON object이며 top-level 형식은 다음과 같다.

```json
{
  "timestamp": "2026-07-23T12:00:00Z",
  "mode": "MIMIC",
  "recording_state": "RECORDING",
  "landmarks": {},
  "motor_state": {},
  "safety_state": {},
  "control_state":{},
  "recording": {}
}
```

- `timestamp`: Web Bridge가 snapshot을 생성한 RFC 3339 UTC `Z` 시각
- `mode`: `DISABLED|MIMIC|MANUAL|TELEOP`
- `recording_state`: 현재 RecordingState의 symbolic state
- `landmarks`: 최신 HandLandmarks 기반 표시 객체
- `motor_state`: 최신 7개 모터 상태의 표시 객체
- `safety_state`: 현재 SafetyState·원인·reset 가능 여부의 표시 객체
- `control_state`: `ControlState.msg` 원문
- `recording`: `RecordingState.msg` 원문. 단 `active_session_id`·`last_session_id`(ROS `uint64`)는 10진 문자열로 직렬화하며 세션 없음은 `“0"`으로 표현한다.
- 아직 유효 데이터를 받지 못한 객체는 `null` 대신 `{}`를 사용한다. 새 snapshot은 같은 연결의 이전 snapshot을 대체한다.
- 이 top-level 여덟 필드는 MVP 계약으로 고정한다. `control_state`·`recording`은 각각 `ControlState.msg`·`RecordingState.msg` 원문을 그대로 싣고(6.3절·FR-30 동결 스키마 기준), 파생 표시 객체인 `landmarks`·`motor_state`·`safety_state` 세 객체의 세부 field와 클라이언트→서버 mode·gesture·recording 요청 JSON은 개발 중 확정하되 기존 ROS 2 서비스·액션에만 매핑하고 통합 시험 전에 `docs/interfaces.md`에 동결한다.
- top-level `mode`는 `control_state.active_mode`(상수 `MODE_*`의 접두사 제거형), `recording_state`는 `recording.state`(상수 심볼)에서 파생한 표시용 mirror이며 두 표현은 항상 일치한다. `landmarks`·`motor_state`·`safety_state`만 표시 객체로 두는 이유는 SafetyState의 reset 가능 여부·reason과 hand-loss latch가 develop 스키마 밖 파생값(FR-41·line 741)이기 때문이며, `control_state`·`recording`은 원문만으로 FR-19·24·26의 owner·Session ID·판정 대기 표시 요구를 충족한다.
- `landmarks`의 출처가 `web_bridge_node`의 `/thing/landmarks` 구독

### 6.5 데이터 저장·EC2 REST 인터페이스

#### 로봇 로컬 저장과 실행 중 상태

로봇에는 별도의 애플리케이션 SQLite, `session_state.json`, 영구 upload outbox 및 spool을 두지 않는다.

- 경로: `ROBOT_DATA_DIR=/var/lib/thing-robot-data`
- 영구 저장 대상: rosbag2 원본과 회전 로그
- 임시 저장 대상: `/var/lib/thing-robot-data/tmp-upload/{session_id}/`의 metadata JSON·HandCommand CSV·MotorStatus CSV, LandMark JSON
- ROS 2 Humble의 rosbag2가 내부 기록 파일로 `.db3`를 생성할 수 있으나 이는 rosbag2 저장 포맷이며 세션·조회·업로드 상태를 관리하는 애플리케이션 DB가 아니다.
- 활성 Session ID, bag path, 기록 상태와 판정 대기는 Logger 실행 중 메모리와 RecordingState로 관리한다. 정상 Stop 후에는 `RecordingState.state=COMPLETED`, `result_pending=true`로 판정을 기다린다.
- StartRecording은 고유 Session ID·경로 확보와 rosbag2 시작이 모두 성공할 때만 수락한다.
- SetMimicResult 수락 후 `thing-control`의 Logger 측 exporter가 rosbag2를 읽어 임시 네 파일을 생성·검증한다. export와 Unix socket handoff는 제어·안전 callback을 차단하지 않는다. HTTPS POST와 EC2 응답 검증은 격리된 uploader가 담당한다.
- exporter는 네 파일을 최종 파일명으로 rename한 뒤 완료 파일 경로와 `content_digest`를 `/run/thing-uploader/uploader.sock`의 private Unix socket으로 전달한다.
- `thing-data-uploader`는 rosbag2를 mount하지 않고 임시 네 파일 디렉터리를 읽기 전용으로 mount한다. uploader는 전달받은 완료 네 파일만 HTTPS POST한다.
- exporter는 완료된 canonical 네 파일의 경로와 파일 정보를 `/run/thing-uploader/uploader.sock`의 private Unix socket으로 전달한다. uploader는 rosbag2에 접근하지 않고, 전달받은 완료 파일만 HTTPS POST한다.
- 실패 시 임시 네 파일을 정리하고 진단 로그를 남긴다. 프로세스 재시작 전 상태와 실패 upload를 자동 복원하지 않는다.
- uploader는 handoff 요청에 대해 session_id, accepted, reason으로 구성된 ACK를 반환한다. handoff 시도가 종료되면 exporter worker는 성공 여부와 관계없이 임시 canonical 네 파일을 정리한다. 완료된 원본 rosbag2는 보존하며, 프로세스 재시작 전 상태와 실패한 업로드는 자동으로 복원하지 않는다. MVP에서는 수동 재업로드 CLI를 제공하지 않는다.

#### HTTPS REST API

```
POST /api/v1/uploads/sessions
GET  /api/v1/sessions
GET  /api/v1/sessions/{session_id}
GET  /api/v1/sessions/{session_id}/data?dataset=hand_command|motor_status&cursor=&limit=
GET  /api/v1/sessions/{session_id}/download/{file_kind}
GET  /health
```

- POST만 `Authorization: Bearer <device-token>`과 `Idempotency-Key: <robot_id>:<session_id>:<data_version>:<content_digest>`를 요구한다.
- public GET은 IP당 분당 120회, upload POST는 token당 분당 10회를 기본으로 제한하고 초과 시 `429`와 `Retry-After`를 반환한다.
- GET은 로그인 없이 READY만 읽기 전용으로 제공한다.
- `file_kind`는 `metadata|hand_command|motor_status|landmark` enum이며 경로 입력을 받지 않는다.
- 목록 기본 20개·최대 100개, `started_at DESC, session_id DESC`
- exact Session ID 검색은 Must; 날짜·결과 필터와 cursor pagination은 Should
- data 기본 1000행·최대 5000행, timestamp 오름차순; 결측 숫자는 JSON `null`

#### 공개 GET 응답 JSON schema v1

모든 Session ID는 문자열, 모든 시각은 RFC 3339 UTC `Z`다. `next_cursor`는 서버가 발급하는 opaque 문자열이며 다음 페이지가 없으면 `null`이다. 클라이언트는 cursor 내부 형식을 해석하지 않는다.

목록 `GET /api/v1/sessions`:

```json
{
  "items": [
    {
      "session_id": "123456789012345678",
      "robot_id": "THING-001",
      "started_at": "2026-07-29T00:00:00.000Z",
      "ended_at": "2026-07-29T00:01:00.000Z",
      "uploaded_at": "2026-07-29T00:01:06.000Z",
      "result": "SUCCESS",
      "duration_ms": 60000,
      "row_counts": {"hand_command": 1200, "motor_status": 4200},
      "file_sizes": {"metadata": 980, "hand_command": 1234, "motor_status": 5678}
    }
  ],
  "next_cursor": null
}
```

상세 `GET /api/v1/sessions/{session_id}`:

```json
{
  "session_id": "123456789012345678",
  "robot_id": "THING-001",
  "schema_version": 1,
  "data_version": 1,
  "started_at": "2026-07-29T00:00:00.000Z",
  "ended_at": "2026-07-29T00:01:00.000Z",
  "uploaded_at": "2026-07-29T00:01:06.000Z",
  "result": "SUCCESS",
  "duration_ms": 60000,
  "interface_commit": "626c59e09f108e6e5eb6d2313efe28bf0e51ed03"
  "time_sync": true,
  "content_digest": "sha256:hex-64",
"row_counts": {
  "hand_command": 1200,
  "motor_status": 4200,
  "landmark": 1200
},
"file_sizes": {
  "metadata": 980,
  "hand_command": 1234,
  "motor_status": 5678,
  "landmark": 12345
},
"downloads": {
  "metadata": "/api/v1/sessions/123456789012345678/download/metadata",
  "hand_command": "/api/v1/sessions/123456789012345678/download/hand_command",
  "motor_status": "/api/v1/sessions/123456789012345678/download/motor_status",
  "landmark": "/api/v1/sessions/123456789012345678/download/landmark"
}
}
```

시계열 `GET /api/v1/sessions/{session_id}/data`:

```json
{
  "session_id": "123456789012345678",
  "dataset": "hand_command",
  "columns": ["stamp_sec", "stamp_nanosec", "elapsed_ms", "sequence", "source", "thumb_flex", "thumb_opp", "thumb_abd", "index_flex", "middle_flex", "ring_flex", "little_flex", "speed_limit", "confidence"],
  "rows": [
    {
      "stamp_sec": 1785283200,
      "stamp_nanosec": 0,
      "elapsed_ms": 0,
      "sequence": 1,
      "source": "VISION",
      "thumb_flex": 0.1,
      "thumb_opp": 0.2,
      "thumb_abd": 0.0,
      "index_flex": 0.3,
      "middle_flex": 0.3,
      "ring_flex": 0.2,
      "little_flex": 0.2,
      "speed_limit": 0.5,
      "confidence": 0.92
    }
  ],
  "next_cursor": null
}
```

`dataset=motor_status`의 `columns`와 각 row key는 아래 MotorStatus CSV header와 동일하다. 정수·실수·boolean은 JSON 기본 타입을 사용하고 읽기 실패 숫자는 `null`이다. 목록·상세·시계열 응답에 정의되지 않은 필드를 MVP 클라이언트가 필수로 가정하지 않는다.

#### multipart 업로드

- `metadata`: `application/json`, 최대 256KiB
- `hand_command`: `text/csv`, 최대 20MiB
- `motor_status`: `text/csv`, 최대 60MiB
- `landmark`: `application/json`, 최대 120MiB
- 네 multipart part의 합계는 최대 200.25MiB다. Django request 제한은 210MiB, Nginx client_max_body_size는 220MiB로 설정한다.
- Django 85MiB, Nginx 90MiB + 120MiB
- 마지막 landmark.json 의 용량 등에 대해서 논의 필요

누락·추가 part와 rosbag2를 거부하고 클라이언트 파일명은 저장에 사용하지 않는다.

#### metadata JSON schema v1

```json
{
  "schema_version": 1,
  "data_version": 1,
  "robot_id": "THING-001",
  "session_id": "123456789012345678",
  "started_at": "2026-07-29T00:00:00.000Z",
  "ended_at": "2026-07-29T00:01:00.000Z",
  "result": "SUCCESS",
  "interface_commit": "626c59e09f108e6e5eb6d2313efe28bf0e51ed03",
  "time_sync": true,
  "content_digest": "sha256:hex-64",
  "files": {
    "hand_command": {
      "filename": "session_123456789012345678_hand_command.csv",
      "size_bytes": 1234,
      "row_count": 1200,
      "sha256": "0000000000000000000000000000000000000000000000000000000000000000"
    },
    "motor_status": {
      "filename": "session_123456789012345678_motor_status.csv",
      "size_bytes": 5678,
      "row_count": 4200,
      "sha256": "0000000000000000000000000000000000000000000000000000000000000000"
    },
    "landmark": {
      "filename": "session_123456789012345678_landmark.json",
      "size_bytes": 12345,
      "row_count": 1200,
      "sha256": "0000000000000000000000000000000000000000000000000000000000000000"
    }
  }
}
```

- Session ID는 ROS `uint64`지만 JSON·API·EC2 SQLite에서는 문자열이다.
- 시간은 RFC 3339 UTC `Z`, `ended_at>started_at`; result는 SUCCESS 또는 FAILURE다.
- `schema_version`과 `data_version`은 이번 MVP에서 1로 고정한다.
- `content_digest`는 `exported_at`과 `content_digest` 자신을 제외한 metadata의 의미 필드 전체를 key 오름차순·공백 없는 UTF-8 canonical JSON으로 직렬화한 뒤 SHA-256으로 계산한다. 두 CSV의 filename·size_bytes·row_count·sha256은 계산 대상에 포함한다.
- 따라서 같은 rosbag2와 같은 SUCCESS·FAILURE 판정은 수동 재생성 시 `exported_at`이 달라져도 같은 `content_digest`를 가져야 한다.
- 서버는 metadata와 실제 두 CSV를 검증해 `content_digest`를 다시 계산한다. token의 robot과 `robot_id`가 일치해야 한다.
- 장치 token은 최소 32바이트 CSPRNG로 생성하고 EC2에는 hash만 비교 가능한 형태로 보관한다. 유출 시 교체한다.

#### CSV 규칙

UTF-8 without BOM, RFC 4180 quoting, comma, header 1행, LF, 소수점 `.`, bool `true|false`를 사용한다. NaN·Infinity를 금지하고 읽기 실패 숫자는 빈 칸으로 둔다. 각 행은 Session ID, UTC Unix stamp와 `elapsed_ms`를 포함하며 timestamp는 비감소여야 한다.

HandCommand CSV:

```
session_id,stamp_sec,stamp_nanosec,elapsed_ms,sequence,source,thumb_flex,thumb_opp,thumb_abd,index_flex,middle_flex,ring_flex,little_flex,speed_limit,confidence
```

MotorStatus CSV:

```
session_id,stamp_sec,stamp_nanosec,elapsed_ms,frame_id,motor_id,actuator_name,goal_position_raw,present_position_raw,goal_position_rad,present_position_rad,velocity_rad_s,current_ampere,voltage_volt,temperature_celsius,torque_enabled,hardware_error,communication_result,communication_ok,bus_communication_ok,failed_read_count
```

MotorStatus 한 수신 시각의 motor 하나를 한 행으로 평탄화한다. 자유 문자열 `MotorStatus.message`, landmark와 상태 이력은 EC2 CSV에 넣지 않는다.

#### EC2 저장·원자성

- unique key: `(robot_id, session_id)`, data version은 1 고정
- SQLite: `/var/lib/thing-data/db.sqlite3`
- 파일: `/var/lib/thing-data/sessions/{robot_id}/{session_id}/`
- staging에 streaming 저장하며 크기·content type·schema·header·행 수·SHA-256과 `content_digest`를 검증한다.
- 검증 후 같은 파일시스템의 final 경로로 원자적 rename하고 SQLite를 READY로 변경한다. 공개 API는 READY만 읽는다.
- crash 후 final 파일과 STAGING row를 대조해 READY 또는 정리 상태로 복구한다.
- 신규 key는 201, 같은 key·같은 `content_digest`는 기존 READY를 유지하고 200, 같은 key·다른 `content_digest`는 409다. 같은 digest의 200 응답에서는 기존 저장 파일을 덮어쓰지 않는다.

#### 성공·오류 응답

성공:

```json
{
  "session_id": "123456789012345678",
  "data_version": 1,
  "status": "READY",
  "content_digest": "sha256:hex-64",
 "files": {
  "metadata": {
    "sha256": "hex-64",
    "size_bytes": 980
  },
  "hand_command": {
    "sha256": "hex-64",
    "size_bytes": 1234
  },
  "motor_status": {
    "sha256": "hex-64",
    "size_bytes": 5678
  },
  "landmark": {
    "sha256": "hex-64",
    "size_bytes": 12345
  }
},
  "uploaded_at": "2026-07-29T00:01:06.000Z"
}
```

uploader는 HTTP 상태만으로 성공 처리하지 않고 응답의 `session_id`, `data_version`, `status=READY`, `content_digest`가 요청과 일치하는지 확인한다. uploader는 HTTP 상태만으로 성공 처리하지 않고 응답의 session_id, data_version, status=READY, content_digest가 요청과 일치하는지 확인한다. 동일한 완료 rosbag2와 result로 다시 export하면 metadata를 포함한 canonical 네 파일과 content_digest가 동일해야 한다. exporter는 EC2 응답을 직접 검증하지 않는다.

오류:

```json
{"error":{"code":"SESSION_CONTENT_CONFLICT","message":"The session already exists with different content.","details":[]},"request_id":"request-uuid"}
```

`400` malformed, `401` 인증, `404` 없음, `405` 공개 쓰기, `409` 충돌, `413` 크기, `415` media type, `422` schema·값, `429` rate limit, `500` 내부, `503` DB·디스크 불가를 사용한다. 경로·토큰·stack trace를 응답에 넣지 않는다.

#### 다운로드 파일

정확히 다음 네 개만 공개한다.

- `session_{session_id}_metadata.json`
- `session_{session_id}_hand_command.csv`
- `session_{session_id}_motor_status.csv`
- `session_{session_id}_landmark.json`

OpenAPI·스키마 문서는 세션의 다섯 번째 파일로 세지 않는다.

---

## 7. 시스템 제약사항

### 7.1 하드웨어 제약사항

- 손가락별 여러 관절을 하나의 모터로 구동하므로 encoder 기반 motor-axis angle은 실제 관절각이 아니다.
- 텐던 마찰·늘어남·초기장력, 스풀 반지름, 스프링과 3D 프린팅 공차가 반복성에 영향을 준다.
- 7개 모터의 순간 전류를 감당하는 별도 전원과 CPU 독립 E-Stop이 필요하다.

### 7.2 소프트웨어·배포 제약사항

- ROS 2 Humble과 develop 기준 인터페이스를 사용한다.
- Docker는 Jetson·Raspberry Pi에만 사용하고 Docker Compose는 Raspberry Pi에서만 사용한다.
- EC2는 native Nginx·Gunicorn·Django·React·SQLite를 systemd로 운영한다.
- 로봇에는 별도의 애플리케이션 SQLite·`session_state.json`·영구 upload spool을 사용하지 않는다. rosbag2의 내부 `.db3` 기록 파일은 이 제한의 대상인 애플리케이션 DB가 아니다.
- MediaPipe는 조명·가림·카메라 각도의 영향을 받으며 MVP는 학습 기반 관절 추론을 사용하지 않는다.

### 7.3 네트워크 제약사항

- 내부 Wi-Fi 지연·손실은 제어 안전 조건으로 취급한다. 인터넷 단절 중 업로드 보존·자동 복구는 2주 MVP 범위에서 제외한다.
- Raspberry Pi 안전 판단은 Jetson·웹·EC2 연결에 의존하지 않는다.
- ROS 2 입력은 최신 유효 명령만 사용하고 재연결 뒤 stale 명령을 실행하지 않는다.
- uploader는 outbound HTTPS만 사용하고 EC2는 DDS에 참여하지 않는다.

### 7.4 일정·범위 제약사항

- 잔여 개발 기간은 2주다.
- Must는 통합·실물 검수까지 완료하고 Should는 Must 통과 후 진행한다.
- FR-39·44·45, 고급 차트·필터·부하 시험·다중 data version·rosbag 공개·S3는 최소 검수에서 제외한다.
- 하드웨어·ROS 2·웹·EC2는 병렬 개발하되 최종 주 이전에 최소 한 번 통합한다.

### 7.5 전제조건과 의존성

- U2D2·7모터·전원·카메라·E-Stop 회로가 준비되어야 한다.
- 한 번에 한 사용자의 오른손과 사전 지정 위치의 시험 물체만 지원한다.
- UTC NTP 동기화, EC2 domain·TLS 인증서, 장치 Token과 팀 고정 관리 IP가 필요하다.
- rosbag2·임시 업로드 파일·EC2 저장 파일을 위한 디스크 용량을 사전에 확보한다.

### 7.6 EC2·업로드 제약사항

- 단일 로봇의 판정 완료 세션과 schema/data version 1만 지원한다.
- 공개 파일은 정확히 네 개이고 상태 이력·영상·rosbag2는 제외한다.
- EC2 업로드 실패가 로봇 제어·안전을 중단하지 않아야 한다. 로봇에는 영구 미전송 queue를 두지 않는다. 완료된 rosbag2 원본은 보존하지만, MVP에서는 이를 이용한 수동 재업로드 CLI와 자동 복구 업로드를 제공하지 않는다.
- 성공한 임시 네 파일은 삭제하고 실패 후 남은 임시 파일은 정리할 수 있다. rosbag2 원본은 별도 보존 정책을 따른다. handoff 시도가 종료되면 exporter의 임시 canonical 네 파일을 정리한다. 완료된 rosbag2 원본은 삭제하지 않고 보존한다.
- EC2 공개 데이터의 최종 기준은 READY SQLite row와 final 파일 디렉터리다.
- 공개 443, 제한된 관리 22 외 포트를 열지 않는다.

---

## 8. 품질 속성 및 검증 기준

### 8.1 Must 품질 지표

- 손 검출: 300~700lux, 40~80cm, 오른손 60초 시험에서 평균 20FPS·유효 검출 90% 이상
- 명령: 60초 MIMIC에서 유효 HandCommand 20Hz 이상, stamp 역행·sequence 중복 실행 0건
- 종단 지연: 카메라 frame부터 최초 MotorStatus 반응 30회 P95 300ms 이하
- 파지: 지정 원통과 집기 물체 각각 10회 중 7회 이상 3초 유지
- 손 미검출: confidence 0.70 미만 또는 미검출 150ms 뒤 발행 중단, 단순 재검출·연결 복구만으로 재개 0건. HOLD에서는 Guard 전체 검증 activity가 최대 gap 100ms로 300ms 연속된 경우에만 RUN 자동복귀 성공
- 명령 단절: 20회에서 HOLD 300ms±100ms, SAFE 1000ms±100ms, stale 재실행 0건
- lease: 갱신 중단 뒤 3000ms±200ms에 owner NONE·mode DISABLED·큐 취소
- Safety Reset: HOLD와 원인 유지 중 수락 0건, SAFE·FAULT 원인 해소 1000ms 또는 E-Stop 물리 해제 500ms 뒤 요청 수락·INIT 재검사·READY, 토크·mode·owner·RUN 자동 복원 0건
- E-Stop: INIT·READY·RUN·SAFE에서 CPU와 무관한 전원 차단, 물리 해제만으로 재동작 0건
- 로봇 로컬 저장: 별도 애플리케이션 SQLite·`session_state.json`·영구 spool 생성 0건, rosbag2 원본과 임시 네 파일만 생성
- 직접 업로드: 정상 네트워크에서 판정 수락 후 5초 안에 upload 시도 시작
- 실패 처리: handoff 또는 upload 실패가 제어·안전·rosbag2를 중단하지 않고 진단 로그에 남으며, handoff 시도가 종료되면 임시 canonical 네 파일이 정리되고 완료된 원본 rosbag2는 보존됨
- 네 파일: 대표 60초 세션에서 metadata JSON, HandCommand CSV, MotorStatus CSV, LandMark JSON의 schema·Session ID·UTC·row count·SHA-256과 재계산한 content_digest가 일치
- 멱등성: 같은 key·같은 `content_digest` 재업로드 200·중복 0, 같은 key·다른 `content_digest` 409, 부분 공개 0
- 공개 포털: 대표 세션 목록·상세·기본 표/차트와 정확히 네 파일 다운로드 성공
- 지속성: Raspberry Pi container 재시작 뒤 이전 recording·판정·upload 자동 재개 0건, EC2 service 재시작과 EC2 재부팅 뒤 READY 데이터 유지
- fan-out, timestamp, overlay 동기화, MJPEG 장애 독립성, 영상 미저장 시험

### 8.2 테스트 요구사항

#### 단위 테스트

- 7축 정규화·filter·deadband, hand-loss debounce·reacquire latch
- command source·stamp·sequence·range·speed_limit 검증과 uint32 wrap
- mode·owner 동시 획득, STOP, lease 원자 전이
- 메모리 기반 recording·result pending 전이, 임시 네 파일 생성·성공 후 삭제·시작 시 잔여 임시 파일 정리
- rosbag2→네 파일 변환, CSV header·행 수·SHA-256·UTC·canonical `content_digest`
- exporter→uploader handoff manifest의 디렉터리·파일명·크기·행 수·SHA-256·content_digest와 ACK 필드 검증
- Bearer Token, part·크기·schema 검증, `content_digest` idempotency·오류 응답

#### 통합 테스트

- Jetson→Raspberry Pi DDS, 7모터 최신 목표 추종과 software watchdog
- MIMIC·MANUAL 입력 충돌, recording 중 mode 차단, Gesture 초기 유지 종료·실행 중 새 요청 거부·Gesture 중 STOP
- MIMIC·TELEOP의 HOLD recovery-only activity 300ms, motor 전달 0건, RUN 복귀 직후 다음 명령 hardware-forward. MANUAL HOLD는 executor 취소와 명시적 STOP→RESET을 확인
- hand loss, command loss, lease callback 선행 만료 통지, 모터 통신 3회 실패,  sparse bus callback에서 300ms tick FAULT, 과전류·과온, E-Stop·Reset
- `/thing/reset_safety` Trigger의 `success`·`message`, HOLD에서 Safety Reset 거부, SAFE·FAULT 1000ms·ESTOP 500ms 안정조건,  ESTOP과 다른 fault가 겹친 경우 모든 안정시간, INIT 재검사와 자동 복원 금지
- SROS2 protected topic의 publisher 집합이 정확히 Guard 하나이며 wildcard grant가 없는지 확인
- Logger 재시작 뒤 이전 recording·result pending·upload를 자동 재개하지 않는지 확인
- EC2 STAGING crash, READY 원자 공개, service restart·reboot
- handoff 또는 upload 실패 중에도 로봇 제어·안전·rosbag2가 독립적으로 동작하고 실패 원인이 진단 로그에 남는지 확인
- handoff 성공·거부·연결 실패 각각에서 exporter 임시 canonical 네 파일이 정리되고 완료된 원본 rosbag2는 보존되는지 확인
- uploader가 EC2 성공 응답의 session_id·data_version·status·content_digest를 검증하는지 확인
- 프로세스 재시작 후 실패한 upload가 자동 재개되지 않고 수동 재업로드 CLI가 제공되지 않는지 확인

#### 시스템 테스트

- 편 손·주먹·원통 파지·집기와 10분 연속 동작
- Laptop 내부망 웹의 기본 영상·mode·안전·기록 조작과 `/ws/robot-state` top-level JSON 검증
- 외부망 EC2 공개 목록·상세·기본 데이터 표시·네 파일 다운로드
- Laptop Vite, Jetson `docker run`, Raspberry Pi `docker compose up -d`, EC2 systemd 재시작 절차

### 8.3 최소 검수 조건

다음은 모두 pass여야 MVP 완료다.

1. 모든 Must FR과 Must NFR이 구현되고 develop 커밋 기준 `colcon build`·인터페이스·관련 package test가 통과한다.
2. `/thing/reset_safety` 계약과 SetControlMode lease·STOP 의미가 `docs/interfaces.md`에 반영되고, `thing_control`의 `std_srvs` dependency·`safety_manager` 서비스 서버 구현 및 관련 package test가 후속 MR에서 통과한다.
3. 7논리축 20Hz·P95 300ms와 원통·집기 7/10, 3초 기준을 통과한다.
4. hand loss·명령 단절·lease·FAULT·E-Stop 시험에서 이전 명령·토크·녹화 자동 재개가 0건이다.
5. 로봇에 별도 애플리케이션 SQLite·`session_state.json`·영구 spool이 없고, 활성 세션은 메모리·RecordingState로만 관리되며 재시작 뒤 이전 작업을 자동 재개하지 않는다.
6. 대표 세션 판정 뒤 즉시 업로드되고 metadata JSON·HandCommand CSV·MotorStatus CSV, Landmark JSON 정확히 네 개만 READY로 공개된다.
7. 네 파일의 Session ID·UTC·schema·row count·SHA-256과 `content_digest`가 일치하고 제외 데이터·민감정보가 없다.
8. 인증 401, 공개 쓰기 405, 크기 413, schema 422, 같은 key의 다른 `content_digest` 409와 EC2 STAGING crash 복구가 계약대로 동작한다.
9. Laptop 내부망 웹은 Jetson `/ws/robot-state` WebSocket·MJPEG로 ROS 2 실시간 데이터를 받고, EC2 포털은 HTTPS 공개 GET으로 EC2 READY 데이터만 조회하며 두 웹 모두 DB나 ROS 2 DDS 경계를 우회하지 않는다.
10. Laptop Vite, Jetson Docker, Raspberry Pi Compose, EC2 native systemd가 문서화한 명령으로 기동하고 EC2 재시작 뒤 READY 데이터가 유지된다.
11. 10분 연속 동작에서 치명적 fault·기구 파손·텐던 이탈이 없고 시험 로그·설정·결과를 GitLab 또는 Jira에 남긴다.

Should·Could 미완료는 위 Must 검수를 막지 않는다.

### 8.4 완료 정의

각 Jira 작업은 코드·CAD·문서가 GitLab에 반영되고 목표 하드웨어·환경 시험, 인수 조건, 로그·영상·제한사항, 요구사항 ID와 결과 연결, 팀원 1명 이상 검토를 완료해야 한다. EC2 작업은 API·네 파일·조회 화면·native 배포 중 담당 결과물을 실제 EC2에서 검증해야 한다. secret과 개인 설정 파일을 커밋하지 않는다.

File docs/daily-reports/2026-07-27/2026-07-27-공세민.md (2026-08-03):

# Daily Report

- 날짜: 2026-07-27
- 작성자: 공세민
- 관련 Jira 작업: [S15P11C103-62](https://ssafy.atlassian.net/browse/S15P11C103-62)

## 오늘 한 일

- DYNAMIXEL **XL330-M288** 제어 환경을 구성하고, PC에서 모터 제어 및 정상 동작 여부를 확인함.
- 통신 상태와 모터 상태를 점검하여 이상 여부를 확인함.
- 위치·속도 제어를 위한 DYNAMIXEL SDK 활용 가능성을 검토함.
- Raspberry Pi와 Jetson Orin Nano 적용을 고려하여 U2D2 기반 연결 방식을 정리함.
- 전완부 내부 구성요소의 배치 방향을 검토하고, 모터 및 구동부를 고려한 전완부 배치도 구상을 완료함.

## 결과 및 확인 자료

- 커밋/MR: 해당 없음
- 사진·영상·측정값: XL330-M288의 PC 제어 및 통신 상태 정상 동작 확인

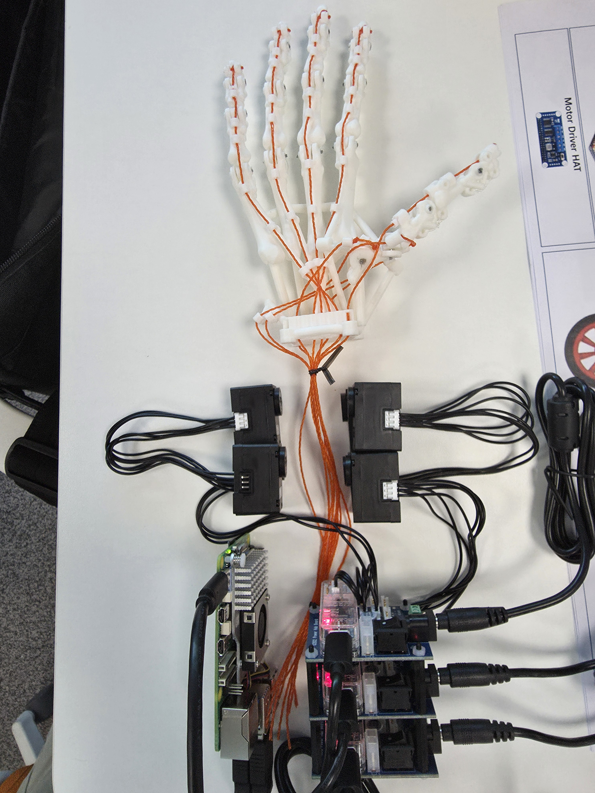
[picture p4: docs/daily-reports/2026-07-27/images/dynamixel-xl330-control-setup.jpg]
DYNAMIXEL XL330-M288 제어 환경


## 막힌 점 또는 위험 요소

- Raspberry Pi 또는 Jetson Orin Nano 환경에서 SDK 기반 제어 코드의 실제 적용 및 검증이 필요함.

## 다음 작업

- 전완부 배치도를 기반으로 상세 치수와 기구 설계를 진행함.
- Raspberry Pi 또는 Jetson Orin Nano 환경에서 SDK 기반 제어 코드를 적용하고 동작을 검증함.

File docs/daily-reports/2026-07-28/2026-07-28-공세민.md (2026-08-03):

# Daily Report

- 날짜: 2026-07-28
- 작성자: 공세민
- 관련 Jira 작업: [S15P11C103-35 한 손가락 텐던 구동 구조 구현](https://ssafy.atlassian.net/browse/S15P11C103-35)

## 오늘 한 일

- 손가락 구동용 spool을 제작하고 XL330 모터를 장착한 뒤, 각 손가락의 텐던을 연결함.
- 엄지·검지·중지·약지·소지 굽힘과 엄지 대립·벌림을 포함한 7축 구성을 정리함.
- 각 손가락이 텐던을 당겨 굽혀지는 방향을 기준으로 모터 ID와 구동 축 구성을 정리함.
- 기존 `calibration` 디렉터리를 정리하고, `~/thing_pjt/motor`에 새 모터 제어 환경을 구축함.
- Python 가상환경 `.venv`를 구성하고 `dynamixel-sdk`를 설치함.
- 7개 모터 스캔, 단일 모터 제어, 키보드 제어, 전체 원위치(2048) 복귀 스크립트를 작성함.
- 키보드 제어에 개별 정지(`Space`)와 전체 정지(`s`) 기능을 추가함.

## 결과 및 확인 자료

- 7개 모터 모두 통신이 정상임을 확인함.
- 각 모터에서 Model `1200`, Operating Mode `5`(전류 기반 위치 제어), Torque OFF 상태를 확인함.
- 모터 제어 기본값을 아래와 같이 설정함.

| 항목 | 설정값 |
| --- | --- |
| Profile Velocity | 300 |
| Profile Acceleration | 1500 |
| Current Limit | 1470 mA |
| Goal Current | 1470 mA |
| Goal PWM | 885 (100%) |

## 막힌 점 또는 위험 요소

- 텐던 장력, 스풀 권취 방향, 손가락별 가동 범위에 따라 같은 목표 위치라도 실제 굽힘량이 달라질 수 있어 축별 위치 보정이 필요함.
- 현재 Torque OFF 상태이므로, 구동 전에는 손가락의 초기 자세와 안전 가동 범위를 확인한 뒤 토크를 활성화해야 함.
- 스풀·텐던 구동부에 손이나 의복이 끼이지 않도록 저전류·저속 조건에서 단계적으로 동작을 검증해야 함.

## 다음 작업

- 각 축의 원점과 안전 최소·최대 위치를 측정해 모터 ID별 제어 범위를 확정함.
- 손가락별 굽힘, 엄지 대립·벌림 및 7축 동시 동작을 저속 조건에서 검증함.
- 텐던 장력과 스풀 권취 상태를 조정하고, 반복 동작 시 텐던 이탈·간섭 여부를 확인함.
- Raspberry Pi 또는 Jetson Orin Nano 환경에서 동일한 SDK 기반 제어 스크립트를 적용·검증함.

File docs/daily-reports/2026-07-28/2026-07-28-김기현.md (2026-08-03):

# Daily Report

- 날짜: 2026-07-28
- 작성자: 김기현
- 관련 Jira 작업: S15P11C103-120

## 오늘 한 일

- **`thing_database_web` 신규 프로젝트 구축**
  - 로봇(라즈베리파이) → EC2 업로드, 회원 → 다운로드 두 가지 신규 요구사항을 구현하는 독립 Django+Vue 프로젝트 생성 (`thing_control_web`과 코드/DB/배포 서버 완전 분리)
  - 백엔드(Django + DRF): `models.py`(`MotorLogFile`, `UserProfile`), `services.py`(`S3Service` — 현재는 로컬 `media/` 폴더를 S3 대역으로 사용하는 스텁 구현, 추후 `boto3` 연동 전환 가능하도록 설계), `views.py`(회원가입/로그인/업로드/다운로드/목록 API) 작성
  - API 설계 및 구현: `/api/register/`, `/api/login/`, `/api/motor-data/upload/`, `/api/motor-data/files/`, `/api/motor-data/download/<id>/`
  - 프런트엔드(Vue 3 + Vite): `HomeView.vue`, `LoginView.vue`, `RegisterView.vue`, `DataDownloadView.vue`, 라우터(`/download` 인증 가드), `services/api.js`/`auth.js` 구현
  - EC2 배포를 전제로 `gunicorn`, S3 설정 뼈대(`AWS_ACCESS_KEY_ID` 등 `.env` 기반) 준비
  - 프로젝트 구조/설계 근거/실행 방법을 README.md 3절에 문서화
- **진행 상태 검증 및 배포 전 항목 일부 수정**
  - [thing_control_web] WS 상태 필드 네이밍 불일치 해소: `HandSocketContext.jsx`, `SafetyBanner.jsx`, `StatusBar.jsx`, `MotorStatusPanel.jsx`, `VisionMode.jsx`, `OrderMode.jsx`의 camelCase 필드(`commandTimeout`, `ownerAlive`, `sequenceRunning`, `busCommunicationOk` 등)를 백엔드(`consumers.py`) 기준 snake_case로 통일

## 결과 및 확인 자료

- 커밋/MR: 해당 없음
- 사진·영상·측정값: 해당 없음 (신규 프로젝트 코드/문서 및 수정 사항, README.md에 구조·API·검증 결과 문서화 / 프런트-백엔드 필드명 grep 검증 결과 camelCase 잔존 없음 확인)

## 막힌 점 또는 위험 요소

- 없음

## 다음 작업

- [thing_database_web] 업로드 API 인증/서명 추가 (`MotorDataUploadView` 등, `permission_classes` 부재로 현재 누구나 호출 가능)
- [thing_database_web] `auth.js`의 `localStorage.isLoggedIn` 기반 로그인 판단을 서버 세션 검증 방식으로 교체
- [thing_database_web] 실제 S3 연동 전환 (`S3Service`의 `upload_file`/`generate_download_url`을 `boto3` 기반으로 교체)
- 실제 배포 환경(EC2)에서 `backend/config/.env` 생성 및 `CORS_ALLOWED_ORIGINS`, `ALLOWED_HOSTS` 등 설정값 확인

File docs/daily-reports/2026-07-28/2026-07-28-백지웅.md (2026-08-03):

# Daily Report

- 날짜: 2026-07-28
- 작성자: 백지웅
- 관련 Jira 작업: S15P11C103-122

## 오늘 한 일

- Raspberry Pi 5에 Ubuntu Server 24.04 LTS 64-bit를 설치하고 초기 시스템 설정을 진행함.
- Raspberry Pi에 Docker Engine과 Docker Compose 실행 환경을 구성함.
- Ubuntu 22.04 Jammy 및 ROS 2 Humble 기반의 Raspberry Pi용 Docker 이미지와 Compose 설정을 구성함.
- 프로젝트 저장소의 `thing_ws`를 컨테이너의 `/thing_ws`에 bind mount하도록 경로를 설정함.
- Dynamixel 통신을 위해 호스트의 `/dev/ttyUSB0` 장치를 컨테이너에 연결하도록 설정함.
- CycloneDDS, `ROS_DOMAIN_ID=103` 및 host network 기반의 ROS 2 통신 환경을 구성함.
- `colcon build` 과정에서 발생한 `ament_cmake` 탐색 오류를 확인하고 ROS 환경 source 및 빌드 의존성 설치를 통해 해결함.
- 새 컨테이너 셸에서 ROS 2와 워크스페이스 환경이 자동 적용되도록 `/root/.bashrc` 설정을 Docker 이미지에 추가함.
- Ubuntu 설치부터 Docker 이미지 빌드와 ROS 2 통신 확인까지의 Raspberry Pi 환경 구성 절차를 문서화함.

## 결과 및 확인 자료

- 커밋/MR: 작성 예정
- 사진·영상·측정값:
  - Raspberry Pi 5에서 Docker 컨테이너 생성 및 실행 확인
  - ROS 2 Humble 워크스페이스 `colcon build` 정상 완료
  - Docker 설정 경로: `/home/rpi103/rpi-ros2-humble`
  - ROS 2 워크스페이스 경로: `/home/rpi103/thing_pjt/thing_ws`

## 막힌 점 또는 위험 요소

- 현재 Compose 설정이 `/dev/ttyUSB0`에 의존하므로 장치 연결 순서에 따라 이름이 변경될 수 있음. 추후 USB 장치 ID를 기준으로 대상 장치를 식별하여 컨테이너에 연결하도록 개선이 필요함.
- `cyclonedds.xml`에 등록된 네트워크 인터페이스와 피어 IP가 실제 장비의 네트워크 구성과 일치하는지 검증이 필요함.
- 컨테이너 재생성 후에도 빌드 의존성과 ROS 환경 설정이 유지되는지 최종 확인이 필요함.

## 다음 작업

- 새 Docker 이미지를 다시 빌드하고 컨테이너를 재생성하여 ROS 환경 자동 source 여부를 확인함.
- 컨테이너에서 Dynamixel 장치 인식 및 SDK 기반 제어 동작을 검증함.
- 다른 ROS 2 장비와 CycloneDDS 기반 토픽 송수신을 테스트함.
- `/dev/serial/by-id` 또는 udev 속성에서 USB 장치 ID를 조회하고, 해당 ID와 일치하는 Dynamixel 장치를 컨테이너에 연결하도록 Compose 실행 방식을 개선함.

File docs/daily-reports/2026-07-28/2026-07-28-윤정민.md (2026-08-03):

# Daily Report

- 날짜: 2026-07-28
- 작성자: 윤정민
- 관련 Jira 작업: [S15P11C103-121](https://ssafy.atlassian.net/browse/S15P11C103-121)

## 오늘 한 일

- Jetson Orin Nano Super의 아키텍처와 시스템 버전을 확인하고, `aarch64`·L4T `36.4.7` 환경에서 `dustynv/ros:humble-desktop-l4t-r36.4.0` 이미지를 사용할 수 있는지 검토함.
- Docker 이미지를 manifest digest `sha256:b8ee30b1ae189cfeeea755a7fd6b8aea74267f5c1bc0cfa4f19a6acec9d941e5`로 고정하여 내려받고, 이미지의 `arm64` 아키텍처와 digest 일치 여부를 확인함.
- NVIDIA Container Runtime으로 ROS 2 Humble 컨테이너를 실행하고 RViz2, `rmw_cyclonedds_cpp`, CUDA 드라이버 라이브러리와 TensorRT `10.4.0`을 확인함.
- 반복 개발을 위해 `thing-jetson-full` persistent 컨테이너 실행 스크립트를 구성함. NVIDIA runtime, host network, `ROS_DOMAIN_ID=103`, CycloneDDS RMW, X11 화면 출력, 웹캠 및 Jetson 호스트 파일 접근 설정을 적용함.
- 컨테이너에서 RViz2를 실행하여 Jetson 물리 화면 출력과 OpenGL `4.6` 사용을 확인함.
- `/dev/video0`과 `/dev/video1`을 확인하고, OpenCV로 `/dev/video0`의 `640×480 @ 30 FPS` 영상 입력과 실시간 GUI 출력을 검증함.
- MediaPipe Hands 실행용 Python 가상환경과 `webcam_mediapipe.py`를 구성함. Jetson 전용 pip 저장소의 DNS 오류를 확인한 뒤, 명령 단위로 공식 PyPI를 지정하여 MediaPipe `0.10.9`와 호환 의존성을 설치함.
- 웹캠 영상에서 손 1개의 21개 랜드마크, handedness와 confidence를 실시간으로 표시하는 동작을 확인함.

## 결과 및 확인 자료

- 커밋/MR: 작성 예정
- 사진·영상·측정값:
  - Jetson: NVIDIA Jetson Orin Nano Super, `aarch64`, L4T `36.4.7`
  - 컨테이너: ROS 2 Humble, `rmw_cyclonedds_cpp`, CUDA 로드 정상, TensorRT `10.4.0`
  - RViz2: Jetson 물리 화면 출력 및 OpenGL `4.6` 확인
  - 웹캠: `/dev/video0`, `640×480 @ 30 FPS` 입력 확인
  - MediaPipe Hands 사진 촬영 시점 표시값: `16.1 FPS`, `Hands: 1`, `Right 0.91`

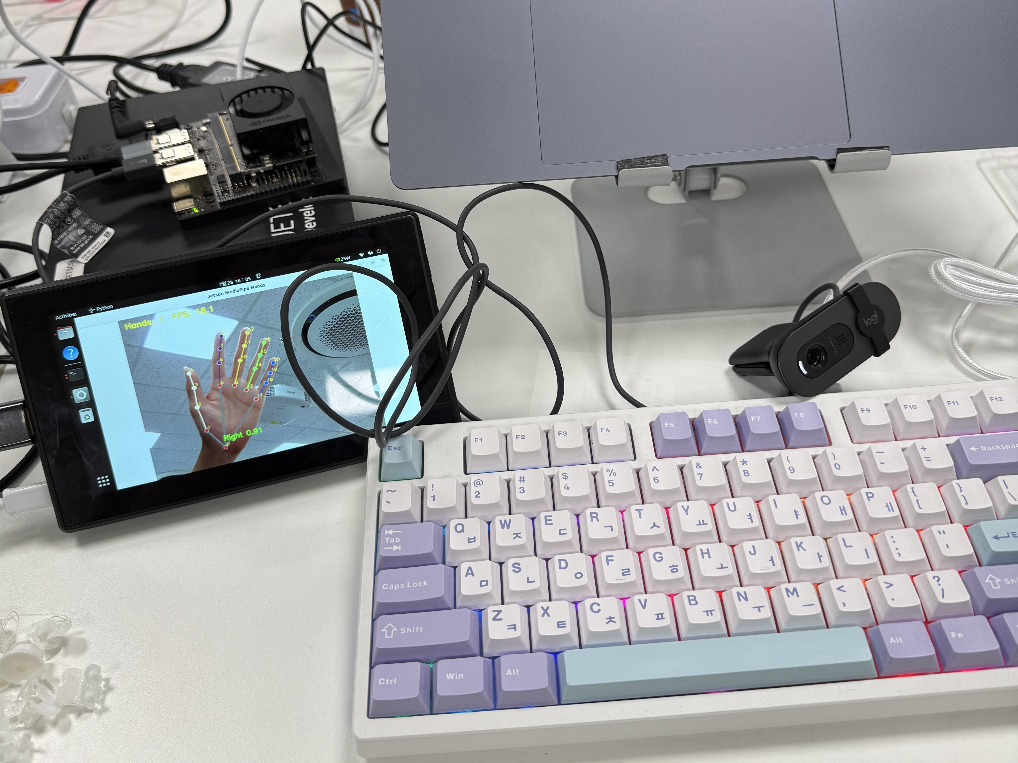
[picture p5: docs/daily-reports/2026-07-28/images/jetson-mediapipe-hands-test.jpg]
Jetson 컨테이너 MediaPipe Hands 실행 결과


## 막힌 점 또는 위험 요소

- Jetson 이미지의 기본 pip 저장소가 `jetson.webredirect.org`로 설정되어 있었고 DNS 조회가 실패하여 일반 Python 패키지를 찾지 못함. 전역 설정을 지우지 않고, 일반 패키지 설치 명령에서만 공식 PyPI를 지정해 우회함.
- `thing-jetson-full` 컨테이너는 개발 편의를 위해 privileged 권한과 호스트 파일 시스템 쓰기 권한을 사용하므로, 컨테이너 내부의 잘못된 명령이 Jetson 호스트에 직접 영향을 줄 수 있음.
- 현재 설치한 패키지는 persistent 컨테이너 내부 상태에 의존하므로, 컨테이너를 `--recreate`하면 설치 내용이 사라질 수 있음. 재현 가능한 설치 절차를 별도 스크립트나 이미지 정의로 정리할 필요가 있음.
- MediaPipe의 `16.1 FPS`는 사진 촬영 시점의 표시값이며, 장시간 평균 성능 측정 결과는 아님.
- 여러 PC 사이의 CycloneDDS 통신은 Jetson IP를 peer 목록에 반영한 뒤 실제 팀 장비를 연결하여 최종 검증해야 함.

## 다음 작업

- Jetson의 실제 LAN IP를 `cyclonedds.xml` peer 목록에 반영하고, `ssafy-worker`와 `ROS_DOMAIN_ID=103` 기반 토픽 송수신을 확인함.
- MediaPipe Hands의 랜드마크 결과를 ROS 2 토픽으로 발행하고, worker에서 수신·시각화하는 구조를 구현함.
- 카메라 해상도와 MediaPipe 모델 복잡도별 처리 FPS를 일정 시간 측정하여 평균·최소 FPS를 기록함.
- persistent 컨테이너의 패키지 설치 및 실행 절차를 재현 가능한 설정 파일이나 설치 스크립트로 정리함.

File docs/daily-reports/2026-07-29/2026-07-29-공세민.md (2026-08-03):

# Daily Report

- 날짜: 2026-07-29
- 작성자: 공세민
- 관련 Jira 작업: [S15P11C103-114 전완부 부품 3D 프린팅 및 재가공](https://ssafy.atlassian.net/browse/S15P11C103-114)

## 오늘 한 일

- 전완부 내부에 XL330 모터를 장착하기 위한 아크릴 고정부 설계를 완료함.
- 아크릴 고정부를 가공하고, 모터·스풀을 전완부 내부에 장착함.
- 전완부 프레임, 모터 고정부, 로봇 손을 조립하여 실제 조립 구조를 확보함.
- 모터 체결 위치와 전완부 내부 배치를 기준으로 텐던·케이블 경로를 구성함.

## 결과 및 확인 자료

- 전완부 모터 고정용 아크릴 고정부의 설계·가공·조립을 완료함.
- XL330 모터와 스풀의 전완부 내부 장착 위치 및 체결 방향을 확인함.
- 후속 간섭·강도 검증에 사용할 실물 조립 구조를 확보함.

### 전완부 및 로봇 손 조립 상태

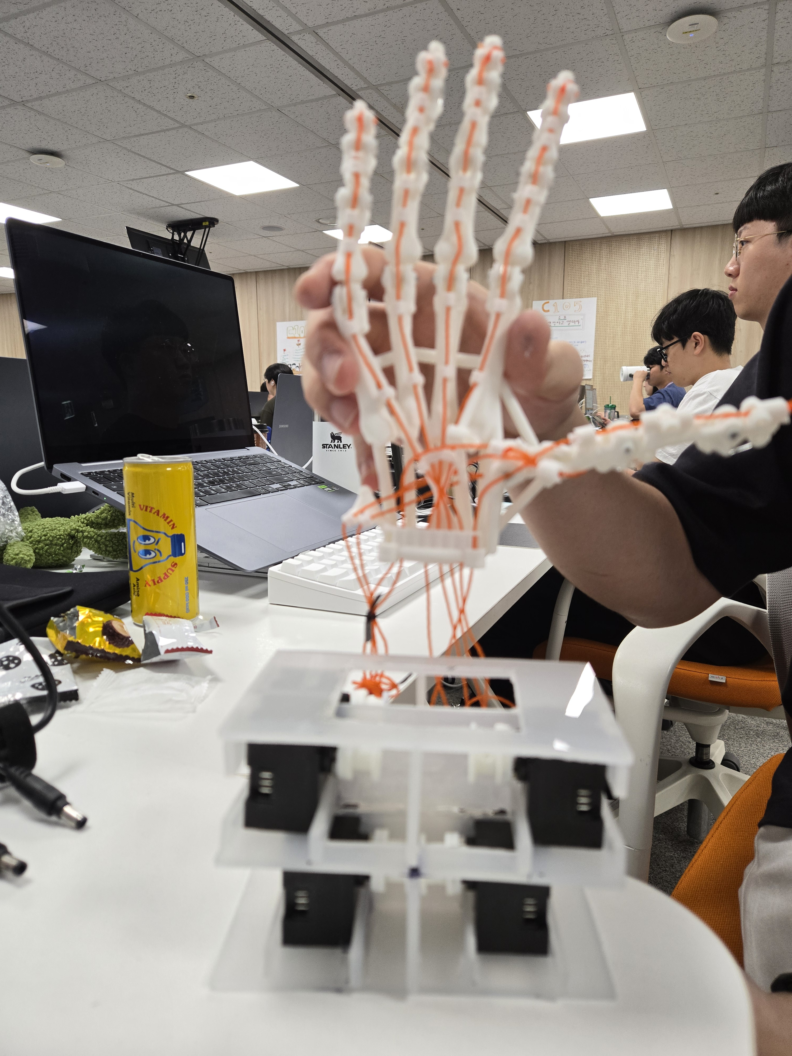
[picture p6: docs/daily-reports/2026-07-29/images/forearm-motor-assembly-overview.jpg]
전완부 모터 고정부와 로봇 손 조립 상태


### 아크릴 고정부 내부 모터·스풀 장착 상태

아크릴 고정부 내부에 장착된 모터와 스풀

### 아크릴 고정부 가공 과정

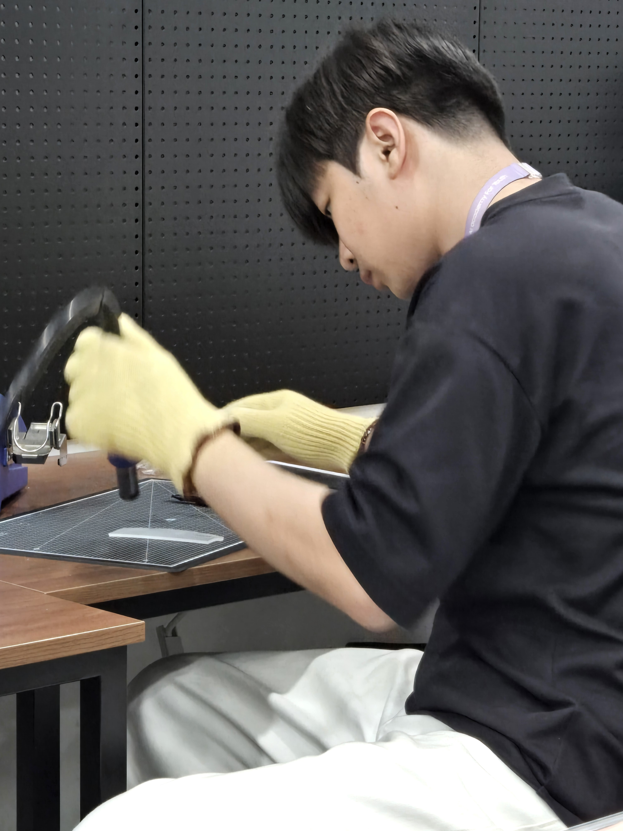
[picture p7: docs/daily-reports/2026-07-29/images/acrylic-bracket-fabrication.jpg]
아크릴 고정부 가공 과정


## 막힌 점 또는 위험 요소

- 실제 구동 시 텐던·케이블·스풀과 전완부 프레임 사이의 간섭 여부를 확인해야 함.
- 반복 구동에서 아크릴 고정부의 변형, 나사 풀림 및 모터 체결 강도를 검증해야 함.
- 검증 결과에 따라 홀 위치, 두께 또는 보강 구조의 재가공이 필요할 수 있음.

## 다음 작업

- 모터 구동 상태에서 텐던·케이블·스풀 간섭을 점검함.
- 반복 동작을 통해 아크릴 고정부와 모터 체결부의 강도를 확인함.
- 검증 결과에 따라 고정부 형상을 보완하거나 재가공함.

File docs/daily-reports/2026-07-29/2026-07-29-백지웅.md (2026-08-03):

# Daily Report

- 날짜: 2026-07-29
- 작성자: 백지웅
- 관련 Jira 작업: [S15P11C103-114](https://ssafy.atlassian.net/browse/S15P11C103-114) 전완부 제작 담당자 작업 협업

## 오늘 한 일

- 본인 담당 이슈는 아니지만 전완부 제작 담당자와 협업하여 로봇 손 아래에 결합할 전완부 구조를 제작함.
- 전완부 내부에 DYNAMIXEL 모터가 들어갈 위치를 정하고, 모터를 수용·고정하는 프레임 구조를 제작함.
- 모터와 스풀이 전완부 내부에서 배치되는 상태를 확인하고, 각 부품이 움직이지 않도록 고정되는 부분까지 완성함.
- 로봇 손을 전완부 위에 임시로 올려 향후 손과 전완부가 연결될 형태와 텐던이 내려오는 방향을 확인함.
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

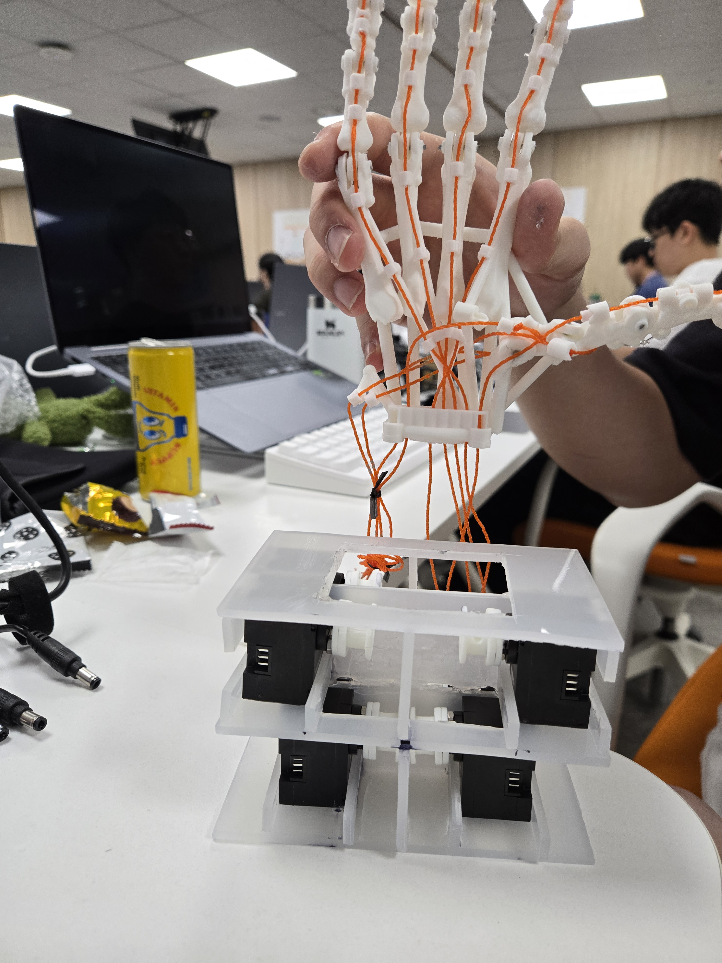
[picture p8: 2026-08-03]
docs/daily-reports/2026-07-29/images/2026-07-29_forearm-motor-mount_hand-placement-preview.jpg

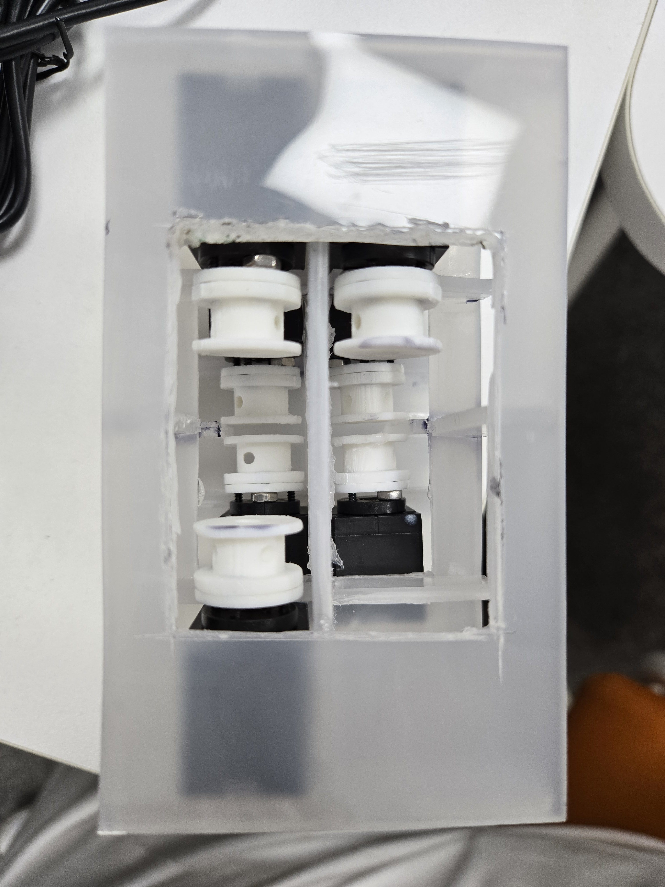
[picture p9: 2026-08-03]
docs/daily-reports/2026-07-29/images/2026-07-29_forearm-motor-mount_internal-detail.jpg

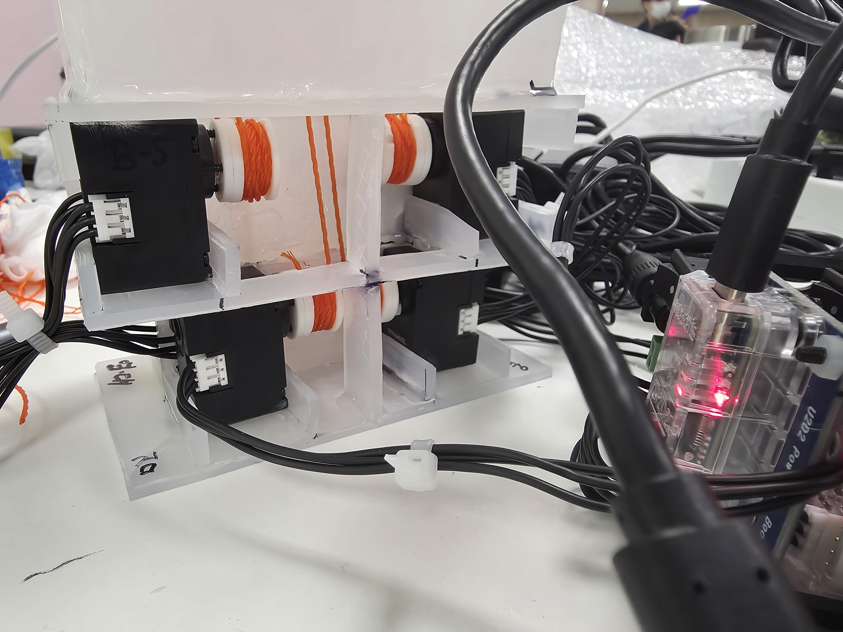
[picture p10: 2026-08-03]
docs/daily-reports/2026-07-31/images/spool-tendon-routing-01.jpg

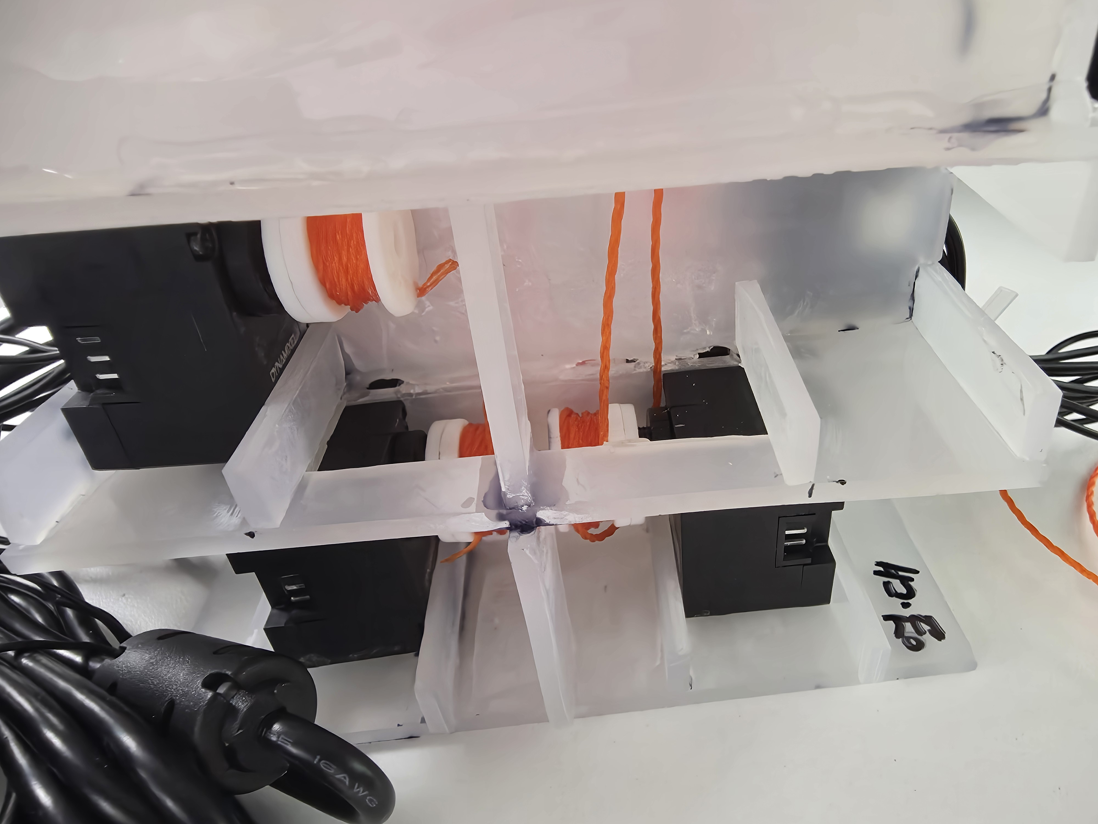
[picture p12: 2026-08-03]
docs/daily-reports/2026-07-31/images/spool-tendon-routing-02.jpg

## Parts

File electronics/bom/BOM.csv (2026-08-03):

category | part | model_or_spec | quantity | status | owner | link | notes
compute | vision_computer | Jetson Orin Nano | 1 | planned |  |  | Camera MediaPipe MJPEG Web Bridge
compute | control_computer | Raspberry Pi 5 | 1 | planned |  |  | Ubuntu 24.04 host and Ubuntu 22.04 ROS 2 Humble container
vision | rgb_camera | USB RGB camera | 1 | planned |  |  | Resolution and FPS to be fixed after measurement
actuator | servo | DYNAMIXEL XL-330-288T | 8 | available |  |  | 7 active axes and 1 spare
interface | usb_dynamixel | DYNAMIXEL U2D2 | 3 | available |  |  | Port and motor grouping managed in motors.yaml
interface | u2d2_hub | U2D2 PHB | 3 | available
power | servo_power_supply | TBD | 1 | planned |  |  | Voltage current rating and fuse must be documented
safety | emergency_stop | NC emergency stop and motor power contactor | 1 | planned |  |  | Must cut motor drive power independently of ROS 2
mechanical | tendon | carpenter thread | 1 | available |  |  | Final material and diameter require test
mechanical | pin | 2mm steel pin | 1 | available |  |  | Quantity to be counted

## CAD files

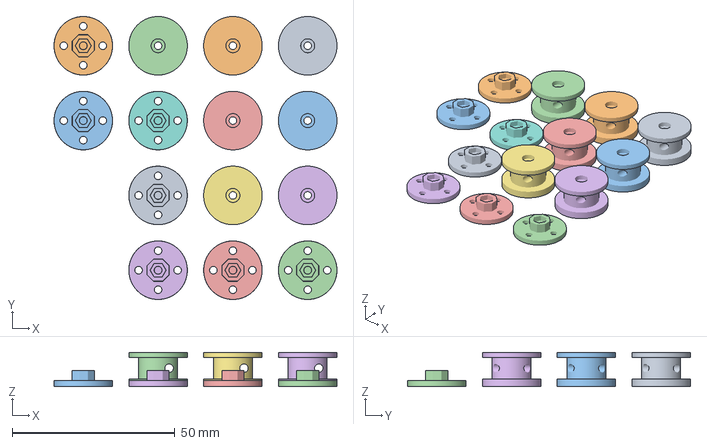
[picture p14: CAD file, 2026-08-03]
mechanical/stl/dynamixel-xl330-spool/xl330_hnx330_n101_2mm_3turn_spool_v3_two_piece_7set_bambu_plate.3mf
87.0 x 87.0 x 10.5 mm
xl330_hnx330_n101_2mm_3turn_spool_v3_two_piece_drum.stl x 7
xl330_hnx330_n101_2mm_3turn_spool_v3_two_piece_mount_base.stl x 7

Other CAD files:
mechanical/stl/dynamixel-xl330-spool/xl330_hnx330_n101_2mm_3turn_spool_v3_two_piece_mount_base.stl
mechanical/stl/version5_2_1/individual/Thing_V5_2_1_18_V52_CAL_BORE_LADDER.stl
thing_ws/src/thing_description/meshes/collision/thumb_proximal.stl
thing_ws/src/thing_description/meshes/visual/thumb_proximal.stl
mechanical/stl/version5_2_1/individual/Thing_V5_2_1_01_V521_PRINT_01_PALM_CORE.stl
thing_ws/src/thing_description/meshes/collision/thumb_distal.stl
thing_ws/src/thing_description/meshes/visual/middle_proximal.stl
mechanical/stl/dynamixel-xl330-spool/xl330_hnx330_n101_2mm_3turn_spool_v3_two_piece_drum.stl
mechanical/stl/version5_2_1/individual/Thing_V5_2_1_07_V521_PRINT_MIDDLE_DISTAL.stl
thing_ws/src/thing_description/meshes/collision/thumb_metacarpal.stl
thing_ws/src/thing_description/meshes/visual/index_middle.stl
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

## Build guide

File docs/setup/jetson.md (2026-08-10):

# Jetson Orin Nano 설정

- JetPack 6.2 / Ubuntu 22.04
- ROS 2 Humble
- RGB 카메라, OpenCV, MediaPipe
- `thing_vision`, `thing_web_bridge`, `thing_logger`(logger 노드·exporter)와
  격리 uploader 데몬(`thing_logger.uploader`, logger와 별도 프로세스 —
  [배치 결정](../decisions/2026-08-05-logger-uploader-jetson-배치.md))

카메라 번호·해상도·FPS는 `thing_bringup/config/vision.yaml`로 관리합니다.
프레임 획득 timestamp와 `camera_color_optical_frame`을 모든 후속 메시지에서
일관되게 사용합니다.

MediaPipe Python 패키지는 Jetson 아키텍처에서 공식 wheel 지원 여부가 달라질 수
있으므로 설치 방법과 검증된 버전을 `vision/requirements.txt`에 고정하기 전에
실제 장치에서 확인합니다.

## Logger와 uploader 실행

uploader 비밀값은 `/etc/thing-uploader.env`에 `KEY=VALUE` 형식으로 둡니다.
Logger와 격리 uploader 프로세스는 다음 명령 하나로 함께 실행합니다.

```bash
ros2 launch thing_bringup logger.launch.py
```

다른 env 파일을 사용할 때만 launch 인자를 지정합니다.

```bash
ros2 launch thing_bringup logger.launch.py \
  uploader_env_file:=/path/to/thing-uploader.env
```

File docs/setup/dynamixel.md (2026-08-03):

# DYNAMIXEL 및 U2D2 설정

## 사전 확인

1. 모터 전원과 Raspberry Pi 전원을 분리합니다.
2. 비상정지가 모터 구동 전원을 실제로 차단하는지 확인합니다.
3. 한 번에 하나의 U2D2와 한 모터로 ID·baud rate를 검증합니다.
4. 중복 ID가 없는 것을 확인한 뒤 7개 모터를 연결합니다.

## USB 권한

장치 이름은 시스템마다 다를 수 있습니다.

```bash
ls -l /dev/ttyUSB* /dev/serial/by-id/ 2>/dev/null
groups
sudo usermod -aG dialout "$USER"
```

그룹 변경 후 로그아웃·로그인합니다. `/dev/serial/by-id` 경로가 제공되면
`/dev/ttyUSB0`보다 안정적이므로 우선 사용합니다.

## 설정 기록

측정한 결과만 `thing_bringup/config/motors.yaml`에 기록합니다.

- 논리축
- motor ID
- U2D2 포트
- 회전 방향
- 최소·최대 raw 위치
- 안전 초기 위치
- 전류·온도 제한

처음에는 낮은 speed limit과 current limit으로 한 축씩 시험합니다.

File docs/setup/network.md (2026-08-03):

# ROS 2 내부망 설정

- 모든 장치에서 같은 `ROS_DOMAIN_ID`를 사용합니다.
- NTP 또는 chrony로 Jetson, Raspberry Pi와 Laptop 시간을 동기화합니다.
- 제어용 네트워크는 프로젝트 내부망으로 제한합니다.
- 장치 IP를 문서에 고정하기 전에 실제 네트워크 담당자와 충돌 여부를 확인합니다.

예시:

```bash
export ROS_DOMAIN_ID=103
export RMW_IMPLEMENTATION=rmw_cyclonedds_cpp
export CYCLONEDDS_URI=file:///absolute/path/to/cyclonedds.xml
```

`thing_bringup/config/cyclonedds.template.xml`을 장치별 로컬 파일로 복사해 사용하고,
개인 네트워크의 IP 목록은 저장소에 직접 commit하지 않습니다.

확인:

```bash
ros2 multicast receive
ros2 multicast send
ros2 node list
ros2 topic list
```

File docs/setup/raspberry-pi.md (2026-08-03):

# Raspberry Pi 5 설정

기본 구성은 Ubuntu 24.04 호스트와 Ubuntu 22.04 기반 ROS 2 Humble 컨테이너입니다.

컨테이너에는 다음 접근이 필요합니다.

- U2D2 USB 장치
- 프로젝트 내부 ROS 2 네트워크
- `thing_ws` 또는 배포된 install workspace
- 장치별 로컬 DYNAMIXEL 설정

모터 안전 제한, timeout과 비상정지는 웹 서버나 Jetson 프로세스가 종료돼도
독립적으로 동작해야 합니다. 컨테이너 재시작 정책을 적용하더라도 모터를 자동으로
RUN 상태로 복구해서는 안 됩니다.

실제 Dockerfile과 compose 설정은 U2D2 장치 경로 및 네트워크 모드를 장치에서
검증한 뒤 별도 Jira 작업으로 추가합니다.

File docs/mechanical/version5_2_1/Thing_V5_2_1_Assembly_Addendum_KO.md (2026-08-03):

# Thing V5.2.1 Closed-Guide 조립·설계 부록

## 1. 문서 범위와 상태

이 문서는 Thing V5.2.1에서 구현된 폐쇄형 힘줄 통로와 분리형 손가락 링크의 조립 방법을 정리한 한국어 부록이다. V5.2의 관절축, 가동 범위, 핀·M2·M3·CMC 인터페이스, 힘줄 작용선과 복귀 동역학은 유지하며, 기존의 측면 삽입 슬롯을 축방향으로 실을 넣는 폐쇄 통로로 변경한 상태를 다룬다.

아래 치수와 수량은 현재 모델의 설계값이다. 디지털 형상·관절 스윕·STL 검증은 통과했지만, 실물 출력성, 인장 강도, 반복 굴곡 수명에 대한 최종 검증 결과는 아직 확정하지 않았으며, 이 문서는 실물 성능 인증을 의미하지 않는다.

## 2. 15개 분리형 링크의 오목 숫자 표기

각 숫자는 손가락 계열을 식별한다. 숫자가 근위·중간·원위 순서를 뜻하지는 않으므로, 세부 링크 구분은 STL 또는 부품 이름을 함께 확인해야 한다. 손바닥과 `THUMB_YOKE`는 아래 15개 숫자 각인 링크에 포함되지 않는다.

| 숫자 | 손가락 | 링크 부품 이름 | 구간 |
|---:|---|---|---|
| 0 | 엄지 | `THUMB_METACARPAL` | 중수골 |
| 0 | 엄지 | `THUMB_PROXIMAL` | 근위지골 |
| 0 | 엄지 | `THUMB_DISTAL` | 원위지골 |
| 1 | 검지 | `INDEX_PROXIMAL` | 근위지골 |
| 1 | 검지 | `INDEX_MIDDLE` | 중간지골 |
| 1 | 검지 | `INDEX_DISTAL` | 원위지골 |
| 2 | 중지 | `MIDDLE_PROXIMAL` | 근위지골 |
| 2 | 중지 | `MIDDLE_MIDDLE` | 중간지골 |
| 2 | 중지 | `MIDDLE_DISTAL` | 원위지골 |
| 3 | 약지 | `RING_PROXIMAL` | 근위지골 |
| 3 | 약지 | `RING_MIDDLE` | 중간지골 |
| 3 | 약지 | `RING_DISTAL` | 원위지골 |
| 4 | 소지 | `LITTLE_PROXIMAL` | 근위지골 |
| 4 | 소지 | `LITTLE_MIDDLE` | 중간지골 |
| 4 | 소지 | `LITTLE_DISTAL` | 원위지골 |

## 3. 폐쇄형 힘줄 통로 35개

총 35개 기능 통로는 일반 폐쇄 가이드 32개와 CMC-B 특수 통로 3개로 구성된다. 힘줄과 라이너는 가능한 열린 끝에서 통로 축을 따라 삽입해야 한다. 관절 간섭을 피해야 하는 `LITTLE_A5` 한 곳은 기존 C형 외피 전체를 메우는 대신, 내부 `Ø2.40 mm` 통로를 완전히 둘러싸는 짧은 폐쇄 포획 링을 사용한다.

| 구분 | 수량 | 소유 부품 | 현재 구현 단면과 유지 사항 |
|---|---:|---|---|
| 일반 폐쇄 가이드 | 32 | 각 해당 링크 | 일정 직경 통로 `Ø2.40 mm` 유지. 축방향 삽입 방식이며 기존 힘줄 중심선·작용선은 유지된다. |
| CMC-B `B_NEG` moving compound | 1 | `THUMB_METACARPAL` | 폐쇄 복합 스웨이지 형상. 상류 `Ø2.40 mm`, 벨마우스 `ID 2.60 → 1.30 mm`, `Ø1.30 mm` 목 구간, 하류 `Ø3.40 mm` 포켓과 스웨이지 스톱을 유지한다. 일반 관통 구멍으로 변경하면 안 된다. |
| CMC-B `B_POS` fixed stepped | 1 | `THUMB_YOKE` | 폐쇄 계단형 PTFE 페룰. 주 통로 `Ø2.40 mm`, 스톱 목 `Ø1.60 mm`, 외경 `5.20 mm`를 유지한다. |
| CMC-B `B_NEG` fixed stepped | 1 | `THUMB_YOKE` | 기존 측면 서비스 슬롯을 닫은 폐쇄 계단형 PTFE 페룰. 주 통로 `Ø2.40 mm`, 스톱 목 `Ø1.60 mm`, 외경 `5.70 mm`를 유지한다. |
| **합계** | **35** |  | **일반 32개 + 특수 3개** |

### 관절 여유를 위한 소형 폐쇄 가이드 두 곳

- `INDEX_A5`, `MIDDLE_A5`, `RING_A5`: 폐쇄부 외경 `Ø4.20 mm`, 내부 `Ø2.40 mm`, 명목 방사 벽 `0.90 mm`의 소형 전장 폐쇄 튜브이다.
- `LITTLE_A5`: 폐쇄부 외경 `Ø4.20 mm`, 내부 `Ø2.40 mm`, 길이 `1.60 mm`의 폐쇄 포획 링이다. 기존 통로 중심을 따라 관절 반대쪽으로 `1.40 mm` 이동해 배치했다. 링 바깥의 기존 C형 외피가 일부 보일 수 있지만, 힘줄은 이 완전 폐쇄 링을 관통하므로 측면으로 빠질 수 없다.
- `THUMB_MCP_BOWDEN_RETENTION`: 폐쇄부 외경 `Ø4.20 mm`, 내부 `Ø2.40 mm`이다. 기존 힘줄 축을 바꾸지 않고 그 축을 따라 중수골 방향으로 `2.00 mm` 이동하여 중수골에 직접 융합했다. 초기 보강 목은 CMC 요크 간섭 때문에 최종 모델에서 사용하지 않는다.

`B_NEG` moving compound의 설계 구간은 통로 축 좌표 기준으로 목이 `t=0.35–0.90 mm`, 하류 포켓 시작이 `t=0.80 mm`이다. `B_POS` fixed stepped는 주 통로 `-2.50–1.80 mm`, 스톱 목 `1.80–2.50 mm`이며, `B_NEG` fixed stepped는 주 통로 `-3.20–1.80 mm`, 스톱 목 `1.60–2.80 mm`이다. 이 겹침과 계단은 종단 및 PTFE 정지 기능을 위한 현재 설계이므로 임의로 드릴 관통하거나 단일 직경으로 보정하지 않는다.

## 4. 축방향 삽입과 관절 핀 조립 순서

폐쇄 통로는 조인트를 결합한 뒤 옆에서 힘줄을 넣을 수 없다. 따라서 다음 순서를 기본 조립 절차로 사용한다.

1. 오목 숫자와 부품 이름을 함께 확인하여 각 링크를 손가락 순서대로 배치한다.
2. 링크를 서로 분리한 상태에서 통로 입구의 버, 브리징 처짐, 서포트 잔여물과 막힘을 확인한다.
3. 필요한 일반 통로마다 짧은 `OD 2.0 mm` PTFE 라이너를 열린 끝에서 축방향으로 삽입한다.
4. 힘줄을 각 라이너와 폐쇄 가이드의 축을 따라 링크별로 순서대로 통과시킨다.
5. 힘줄 경로가 확보된 뒤에만 MCP·PIP·DIP 및 엄지 관절을 정렬하고 관절 핀을 삽입한다.
6. 핀 조립 후 낮은 장력으로 전 가동 범위를 천천히 움직여 힘줄 끼임, 라이너 돌출, 관절 틈을 가로지르는 튜브가 없는지 확인한다.

조립 편의를 위해 힘줄과 라이너를 먼저 끼운 링크들을 관절 순서대로 모아 둔 다음 핀을 체결한다. 통로 옆면을 절개하거나 힘줄을 측면에서 눌러 넣지 않는다.

### CMC-B 특수 통로 조립 주의

- `B_POS/B_NEG` fixed stepped: `OD 2.0 mm` PTFE 라이너를 `Ø2.40 mm` 주 통로에 축방향으로 넣고 `Ø1.60 mm` 스톱 목에서 멈춘다. 라이너가 목을 통과하도록 밀거나 목을 확공하지 않는다. 힘줄만 목을 지나도록 구성한다.
- `B_NEG` moving compound: V5.2에서 이어진 스웨이지 종단, `Ø1.30 mm` 목과 `Ø3.40 mm` 포켓을 보존한다. PTFE 라이너를 작은 목까지 강제로 관통시키지 않으며, 힘줄과 종단 부품은 축방향으로 조립한다.

## 5. 짧은 PTFE 라이너 사용 권장

현재 조립 정책은 링크 단위의 짧은 `OD 2.0 mm` PTFE 라이너 사용을 전제로 한다. 하나의 긴 튜브로 움직이는 관절을 가로지르기보다 링크마다 분리된 짧은 라이너를 사용해야 굴곡 시 튜브가 관절축을 밀거나 유효 모멘트 암을 바꾸는 위험을 줄일 수 있다.

라이너 길이는 현재 모델에서 단일 확정값으로 지정되지 않았다. 실물 링크에 맞춰 다음 조건으로 결정한다.

- 링크 내부 안내 구간은 덮되 관절 틈으로 돌출하지 않을 것
- 핀, 조인트 스톱, 계단형 페룰의 어깨와 간섭하지 않을 것
- 끝단을 직각으로 절단하고 찌그러짐·버를 제거할 것
- 조립 전 힘줄이 라이너 내부에서 손으로 부드럽게 왕복하는지 확인할 것

## 6. 내부 서포트와 슬라이싱 주의

폐쇄되고 기울어진 통로 안에 슬라이서가 생성한 서포트가 들어가면 제거가 어렵고 축방향 삽입이 불가능해질 수 있다. 출력 전 Bambu Studio의 레이어 미리보기에서 `Ø2.40 mm` 주 통로, `Ø1.60 mm` 스톱 목, `Ø1.30 mm` 스웨이지 목과 `Ø3.40 mm` 포켓 내부를 단면별로 확인한다.

- 힘줄 통로 내부에는 슬라이서 서포트가 생성되지 않도록 서포트 차단 영역과 출력 방향을 조정한다.
- 통로 천장의 처짐 또는 브리징 실패 가능성도 레이어 미리보기와 실물 쿠폰으로 확인한다.
- 출력 후 보이지 않는 잔여물을 드릴로 무리하게 밀어내지 않는다. 특히 세 특수 통로의 목과 포켓은 기능 형상이므로 확공 금지 대상이다.
- 모델 생성 과정에서 일반 가이드를 소유 부품에 연결하기 위해 추가된 구조 브리지는 출력물의 일부이다. 이것은 슬라이서가 만드는 제거용 내부 서포트와 다르므로 잘라내지 않는다.

## 7. 디지털 검증 결과와 실물 검증 계획

현재 배포 파일은 다음 디지털 검사를 통과했다.

- 구조 부품 17개와 보정 쿠폰 8개: 단일 메시 아일랜드, 비매니폴드 가장자리 0, 양의 체적.
- 폐쇄 통로 35개: 총 105개 방사 단면에서 내부 반경과 최소 벽 두께 검사 통과.
- 숫자 각인 15개: `0/1/2/3/4`가 각각 3개 링크에 적용되었고, 각인 후 잔여 벽 두께 조건 통과.
- 네 손가락: 4개 손가락 × 4개 자세에서 V5.2 기준에 없던 새 충돌 쌍 0.
- 엄지 굽힘: 4개 자세에서 새 충돌 쌍 0.
- 엄지 CMC: CMC-A와 CMC-B의 5도 간격 90개 조합에서 부품 충돌 0.
- STL: 개별 25개는 각각 수밀 단일 바디, 합본 1개는 25개 바디이며, 총 26개 모두 양의 체적과 일관된 와인딩 검사 통과.

아래 항목은 실제 재료와 출력 조건에서 수행해야 할 물리 검증 계획이다.

아래 항목은 양산 또는 실제 구동 전에 수행해야 할 물리 검증 계획이다. 현재 문서에는 합격 결과를 기록하지 않는다.

| 검증 항목 | 계획된 확인 내용 | 현재 상태 |
|---|---|---|
| 통로 쿠폰 | 상속된 `ID 2.40 mm` 보어 래더 쿠폰을 실제 재료·노즐·레이어 조건으로 출력하고, `OD 2.0 mm` PTFE가 서포트 잔여물 없이 축방향으로 들어가는지 확인 | 미실시 또는 결과 미확정 |
| 특수 단면 쿠폰 | fixed stepped의 PTFE 정지, moving compound의 목·포켓·스웨이지 종단 조립성을 별도 단면 쿠폰으로 확인 | 미실시 또는 결과 미확정 |
| 폐쇄 가이드 인장 | 계획 조건 `30 N`, `60 s × 10회`로 링크별 가이드의 갈라짐, 라이너 이탈과 영구 변형을 검사. 영구 변형 판정 기준은 계획상 `0.20 mm` 초과 여부로 둠 | 미실시 또는 결과 미확정 |
| CMC 스웨이지 검증 | V5.2에서 이어진 계획 게이트인 쿠폰 `90 N` proof와 최종 부품 `30 N`, `60 s × 10회` proof를 실물에서 수행 | 미실시 또는 결과 미확정 |
| 반복 굴곡 | 저하중 전 가동 범위 반복을 계획상 최소 `1,000회` 수행하고 가이드 천장 균열, PTFE 마모·보풀, 끼임과 숫자 각인 식별성을 확인 | 미실시 또는 결과 미확정 |
| 조립 순서 확인 | 모든 링크에서 PTFE와 힘줄을 핀보다 먼저 축방향으로 삽입할 수 있는지 실제 조립으로 확인 | 미실시 또는 결과 미확정 |

시험 하중과 반복 횟수는 현재 검증 계획값이며 확정 성능 수치가 아니다. 재료, 출력 방향, 레이어 접합, 실제 힘줄 및 종단 부품이 정해진 뒤 결과를 기록하고 필요하면 기준을 개정해야 한다.

## 8. 조립·수정 금지 사항 요약

- 폐쇄 통로에 새 측면 슬롯을 만들지 않는다.
- 일반 통로 `Ø2.40 mm`와 세 특수 통로의 계단·복합 단면을 서로 혼동하지 않는다.
- `B_POS/B_NEG` fixed stepped의 `Ø1.60 mm` 스톱과 `B_NEG` moving compound의 `Ø1.30 mm` 목·`Ø3.40 mm` 포켓을 관통 확공하지 않는다.
- PTFE 라이너가 움직이는 관절 틈을 가로지르지 않게 한다.
- 핀을 먼저 조립한 상태에서 힘줄 또는 라이너를 측면 압입하지 않는다.
- 숫자 표기만으로 링크 구간을 판단하지 않고 반드시 부품 이름을 함께 확인한다.

이 부록은 V5.2.1의 현재 구현과 권장 조립 절차를 설명한다. 실제 출력 조건에서 쿠폰, 인장 및 반복 굴곡 검증을 완료하기 전에는 최종 강도나 수명을 보증하지 않는다.

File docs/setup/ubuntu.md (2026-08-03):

# Ubuntu 개발 PC 설정

## 필수 도구

```bash
sudo apt update
sudo apt install git git-lfs python3-colcon-common-extensions python3-rosdep
git lfs install
```

ROS 2 Humble은 Ubuntu 22.04 환경을 기준으로 합니다. Ubuntu 24.04에서는 프로젝트의
Raspberry Pi용 Ubuntu 22.04 컨테이너 또는 별도 22.04 환경을 사용합니다.

## 저장소와 의존성

```bash
git clone --branch develop \
  https://lab.ssafy.com/s15-webmobile3-sub1/S15P11C103.git
cd S15P11C103
git lfs pull
source /opt/ros/humble/setup.bash
cd thing_ws
rosdep install --from-paths src --ignore-src -r -y
```

## 빌드와 시험

```bash
colcon build --symlink-install
source install/setup.bash
colcon test
colcon test-result --verbose
```

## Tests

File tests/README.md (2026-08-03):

# Tests

이 디렉터리는 `procedures/`의 재현 가능한 시험 절차와 `results/`의 측정 결과를 관리합니다.

실험 조건과 측정 결과를 재현 가능한 형태로 기록합니다.

핵심 지표:

- 손 펼침/주먹 반복 횟수
- 시험 물체별 파지 성공률
- 비전 입력부터 서보 동작까지의 지연시간
- tendon 이탈, 서보 과열 및 통신 손실 여부

필수 절차:

- `procedures/grasp-test.md`: 원통 파지와 엄지–검지 집기
- `procedures/safety-test.md`: timeout, SAFE/FAULT와 비상정지
- `procedures/recording-test.md`: rosbag2, Session ID와 판정 상태

시험 결과는 날짜, commit, 설정 파일 버전과 실제 측정값을 `results/`에 남깁니다.

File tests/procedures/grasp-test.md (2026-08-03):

# 파지 및 집기 시험 절차

## 공통 조건

- 시험 일시:
- 시험자:
- 제어 모드:
- 시험 물체 이름·형상:
- 물체 질량·크기·재질:
- 물체 초기 위치와 방향:
- 모터 전압:
- motor ID·위치 제한 설정 버전:
- tendon 장력·spool 설정:
- 소프트웨어 commit:

각 시도는 동일한 초기 자세와 물체 배치에서 시작합니다.

## 원통형 물체 파지

1. 로봇손을 초기 편 손 자세로 이동합니다.
2. 표시된 기준 위치에 원통형 물체를 놓습니다.
3. MIMIC 또는 MANUAL 파지 명령을 실행합니다.
4. 물체를 최소 3초간 유지합니다.
5. 로봇손을 초기 자세로 복귀시킵니다.
6. 총 10회 반복하고 각 결과와 실패 원인을 기록합니다.

## 엄지–검지 집기

1. 로봇손을 초기 편 손 자세로 이동합니다.
2. 표시된 기준 위치에 지정 소형 물체를 놓습니다.
3. 엄지 굽힘·대립축과 검지 굽힘축으로 집기 명령을 실행합니다.
4. 물체를 최소 3초간 유지합니다.
5. 총 10회 반복하고 각 결과와 실패 원인을 기록합니다.

## 성공 기준

- 지정 접촉면으로 물체를 3초 이상 유지해야 합니다.
- 10회 중 7회 이상 성공해야 합니다.
- 내부 품질 목표로 5초 유지 결과도 별도 기록할 수 있습니다.
- 설정 변경이 발생하면 변경 전후 결과를 같은 시험 묶음으로 합산하지 않습니다.

## 결과표

| 회차 | 성공/실패 | 유지시간 | 최대 전류 | 최대 온도 | 실패 원인·비고 |
| ---: | --- | ---: | ---: | ---: | --- |
| 1 |  |  |  |  |  |
| 2 |  |  |  |  |  |
| 3 |  |  |  |  |  |
| 4 |  |  |  |  |  |
| 5 |  |  |  |  |  |
| 6 |  |  |  |  |  |
| 7 |  |  |  |  |  |
| 8 |  |  |  |  |  |
| 9 |  |  |  |  |  |
| 10 |  |  |  |  |  |

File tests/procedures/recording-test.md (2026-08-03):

# 데이터 기록 시험 절차

1. MIMIC 모드에서만 녹화 시작이 허용되는지 확인합니다.
2. 시작 응답 Session ID와 `RecordingState.active_session_id`가 일치하는지 확인합니다.
3. 녹화 중 모든 일반 모드 변경 요청이 거부되는지 확인합니다.
4. rosbag2에 HandLandmarks, HandCommand와 MotorStatus가 포함되는지 확인합니다.
5. 카메라 영상 파일이 생성되지 않는지 확인합니다.
6. 종료 후 `active_session_id=0`과 최근 세션 정보가 발행되는지 확인합니다.
7. 성공·실패 판정 전 다음 녹화가 거부되는지 확인합니다.
8. 판정 후 다음 세션을 시작할 수 있는지 확인합니다.
9. rosbag2를 재생해 timestamp와 메시지 필드를 분석할 수 있는지 확인합니다.

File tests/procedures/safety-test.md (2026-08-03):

# 안전 상태 시험 절차

## 준비

- 로봇손을 고정하고 주변 작업자를 안전거리 밖으로 이동시킵니다.
- 비상정지와 모터 전원 차단이 물리적으로 동작하는지 먼저 확인합니다.
- 낮은 속도·전류 제한과 편 손 안전 자세를 사용합니다.

## 시험 항목

1. 정상 RUN 중 MIMIC 명령을 끊고 200–500ms 설정값에서 timeout을 확인합니다.
2. 짧은 단절에서 HOLD, 장시간 단절에서 SAFE로 전환되는지 확인합니다.
3. 네트워크 복구 후 명시적 재개 입력 없이 움직이지 않는지 확인합니다.
4. 한 모터의 통신을 끊고 해당 motor ID와 FAULT가 표시되는지 확인합니다.
5. 설정된 전류·온도 기준 초과를 모의하여 일반 명령이 차단되는지 확인합니다.
6. 비상정지로 모터 전원이 차단되고 해제 후 자동 재동작하지 않는지 확인합니다.

각 시험에 commit, 설정 파일, timestamp, 상태 토픽과 실제 관찰 결과를 기록합니다.

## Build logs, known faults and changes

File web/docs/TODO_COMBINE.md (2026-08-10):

# 통합 작업 목록

내부망 관제·제어 웹을 실제 로봇에 붙일 때 해야 하는 일입니다. 위에서 아래로 진행합니다.

- `[ ]` 웹 담당이 하는 일
- `[!]` 다른 담당의 회신·구현이 있어야 진행되는 일
- `[·]` 통합 당일 확인만 하는 일

---

# 1. 통합 전 — 웹 담당

## 1.1 미구현 마무리

- [x] **기록 서비스 거부 사유 8종 추가** — 완료
8종(`not_mimic_mode` `start_failed` `already_recording` `result_pending` `not_recording` `session_mismatch` `stop_failed` `owner_lease_expired`)이 `messageProtocol.js` 의 `REJECT_REASON` 과 `describeReason()` 문구표에 반영됨. 남은 확인은 "브릿지가 원문 그대로 싣는가"(pending-decisions E-1) 뿐.
   > `session_mismatch` 는 웹이 이미 가진 `web_session_mismatch` 와 **다른 값**입니다. 둘을 합치지 마십시오.

- [x] **`MotorState.torque_enabled` 표시** — 완료
`MotorStatusPanel` 에 "토크" 열 추가됨. `communication_ok=false` 면 값을 유효로 안 보고 "-" 로 둠(FR-30 인수조건). FR-35 READY·RESET 전이 근거로 통합 중 유용.

- [ ] **NFR-22 이벤트 회전 로그** (Should)
  Must 가 아니므로 통합 후로 미뤄도 됩니다.

## 1.2 상대편에 전달

- [ ] **브릿지 담당에게 `docs/interfaces-bridge.md` 전달**
  1장(브릿지가 해야 하는 것)이 구현 대상입니다. `control_state` 와 `recording` 두 필드가 없으면 **화면이 통째로 잠깁니다.**

- [ ] **`docs/pending-decisions.md` 배포**
  담당별 9건입니다. A-1(snapshot 주기)과 B-1(`speed_limit`)이 우선입니다.

- [ ] **`speed_limit` 은 통합 시험 전 필수**
  FR-32 가 "실제 축 속도는 YAML 최대속도에 이 비율을 곱한다" 로 확정했습니다. 웹이 `open`·`fist` 에 보내는 `1.0` 은 **최대속도 100%** 입니다. 근거 없이 정한 값으로 전속을 내고 있습니다. 텐던 장력에 직결되므로 실물 시험 전에 받아야 합니다.

## 1.3 배포 설정

- [ ] **`.env.local` 작성** (`env.txt` 복사)
  ```
  VITE_WS_URL=ws://<Jetson-IP>:8000/ws/robot-state
  VITE_MJPEG_STREAM_URL=http://<Jetson-IP>:8080/stream/overlay
  VITE_MJPEG_RAW_STREAM_URL=          # 비우면 원본 전환 버튼이 사라집니다
  ```

- [ ] **`npm run dev` 로 띄울지 빌드로 띄울지 정하기**
  `VITE_WS_URL` 을 비우면 `ws://<현재 호스트>/ws/robot-state` 로 폴백하는데, **이를 받아 주는 것은 dev 서버 프록시뿐입니다.** 빌드 산출물이나 `preview` 에는 프록시가 없어 연결되지 않습니다. 빌드로 운영하려면 `VITE_WS_URL` 을 반드시 채웁니다.

- [ ] **Jetson MJPEG 가 http, 페이지가 https 인 경우 확인**
  혼합 콘텐츠로 브라우저가 영상을 막습니다. 내부망이라 둘 다 http 면 문제없습니다.

- [ ] **`npm test` `npm run build` `npm run lint` 통과 확인** (현재 151건)

---

# 2. 통합 전 — 다른 담당

- [!] **브릿지: `interfaces-bridge.md` 1장 구현**
  snapshot 6.4절 고정 6필드 + `control_state` + `recording`. `.msg` 원문 dump 로 보내면 됩니다.

- [!] **브릿지: snapshot 을 주기 발행으로**
  값이 안 바뀌어도 계속 보내야 합니다. 변경 시에만 보내면 **로봇이 멀쩡해도 화면이 상시 "연결 끊김"** 입니다.

- [!] **브릿지: `session_id` 를 JSON 문자열로**
  6.5절입니다. 숫자로 보내면 63-bit 값이 `JSON.parse` 시점에 손상되고 웹이 기록 종료·판정 전송을 차단합니다.

- [!] **브릿지: ack 의 `request_id` 를 요청과 동일하게**
  웹이 이 값으로 버튼 잠금을 풉니다. 없으면 2초 타임아웃으로만 풀립니다.

- [x] **`.msg`/`.srv` 최신본 확인** — 완료
  2026-08-04 최신본 반영(pending.js C-1·C-3·C-4·C-6 확정 제거). `SetControlMode` 요청은 `requested_mode`/`requested_owner`, `ControlState` 는 `active_mode`/`active_owner` 로 확인됨.

- [!] **스펙: 동시 접속 처리 결정** (D-1)
  `owner` 가 `WEB` 하나뿐이라 탭이 두 개면 둘 다 제어권 보유로 인식합니다. 웹에서 해결할 수 없습니다. 브릿지가 연결 하나만 허용하는 것이 가장 간단합니다.

---

# 3. 첫 접속 — 순서대로

브라우저 콘솔을 열고 시작합니다. **조용히 실패하는 경로를 전부 없앴으므로, 화면이 이상하면 콘솔에 이유가 있습니다.**

## 3.1 기동 확인

- [·] 콘솔에 시작 표가 나오는가 (`[진단] 내부 제어 웹 시작 — 현재 가정값`)
      WS·MJPEG 주소와 파생 임계값 4개가 표시됩니다. 주소가 `(미설정)` 이면 `.env.local` 을 확인합니다.

## 3.2 WebSocket 연결

- [·] 상단 우측이 **연결됨** 인가
- [·] `WS_ERROR` 진단이 없는가 → 있으면 주소·브릿지 기동·방화벽

## 3.3 snapshot 수신

콘솔에 아래가 나오면 각각 다음을 뜻합니다.

| 진단 | 뜻 | 조치 |
|---|---|---|
| `WS_UNRECOGNIZED_MESSAGE` | **`mode` 가 문자열이 아님** → snapshot 전체가 버려짐 | 브릿지가 `mode`·`recording_state` 를 symbolic string 으로 |
| `SNAPSHOT_MISSING_FIXED_FIELDS` | 6.4절 고정 필드 누락 | 미수신 객체는 `null` 이 아니라 `{}` 로 |
| `SNAPSHOT_NO_CONTROL_STATE` | **조작이 전부 잠김** | `ControlState.msg` 원문을 `control_state` 로 |
| `SNAPSHOT_NO_RECORDING` | 녹화만 잠김 | `RecordingState.msg` 원문을 `recording` 으로 |
| `UNKNOWN_ENUM_*` | 웹이 모르는 uint8 값 | 매핑표에 상수 추가 |
| `SESSION_ID_NUMERIC` | 63-bit 값 손상 | 10진 문자열로 |
| `HAND_COMMAND_VALUES_WRAPPER` | 7축이 `values` 안에 있음 | 최상위 필드로 (FR-30) |
| `SNAPSHOT_RATE_MISMATCH` | 실측 주기가 가정과 다름 | `pending.js` 의 `BRIDGE_SNAPSHOT_PERIOD_MS` 를 실측값으로 |

- [·] **`SNAPSHOT_RATE_MISMATCH` 가 알려 주는 실측값을 `pending.js` 에 반영**
      이 한 값에서 판정 임계값 4개가 파생됩니다. A-1 회신을 기다릴 필요 없이 여기서 확정됩니다.

## 3.4 표시 확인

- [·] 머리 색이 안전 상태에 따라 바뀌는가
- [·] 8상태 트랙의 표시자가 현재 상태에 있는가
- [·] 장치 표시가 실제 연결과 맞는가 (`단절:` 목록)
- [·] 모터 7채널이 다 나오는가. 값이 이어져 움직이는가

---

# 4. 기능 수용 시험 — 8.3절 대응

## 4.1 제어권 (FR-19 / FR-34)

- [·] MIMIC 보유 중 MANUAL 획득 버튼이 **잠겨** 있는가 (두 단계 강제)
- [·] 정지 → 획득 순서로만 전환되는가
- [·] 페이지 새로고침·재연결 후 **자동 획득이 없는가** (NFR-15·NFR-23)
- [·] 제어권 박동이 1초 주기로 뛰는가. 잃으면 멈추는가
- [·] LOCAL owner(teleop)가 잡고 있으면 `owner_conflict` 로 거부되는가

## 4.2 조작 (FR-22 / FR-23)

- [·] gesture 4종이 실제로 전송되는가 (`execute_gesture`, `gesture_name`)
- [·] 연달아 누르면 `motion_active` 로 거부되는가
- [·] **정지가 잠금과 무관하게 항상 전송되는가**
- [·] `stop_barrier_pending`·`stop_barrier_timeout` 안내가 뜨는가

## 4.3 안전 (FR-27 / FR-35)

- [·] HOLD 에서 자동복귀 조건(300ms·gap 100ms·SAFE 1000ms)과 STOP→RESET 대안을 **함께** 안내하는가
- [·] MANUAL 의 HOLD 에서 "재개용 명령을 스스로 만들지 않는다" 가 나오는가
- [·] RESET(7) 이 `UNKNOWN(7)` 이 아니라 `RESET` 으로 나오는가
- [·] SAFE·FAULT·ESTOP 에서 안전 초기화 버튼이 나오고, READY·RUN 에서는 안 나오는가
- [·] 손 미검출 확정 시 "자동 재개되지 않습니다" 가 나오는가
- [·] **정상 STOP 뒤 재획득이 RESET→READY 순서를 관측한 뒤에만 되는가** (E-2)
      웹은 READY 만 보고 버튼을 엽니다. 눌렀는데 거부되면 그 사유를 알려 주십시오

## 4.4 기록 (FR-18 / FR-26 / FR-40)

- [·] 기록 시작 → 종료 → 성공·실패 판정이 순서대로 되는가
- [·] Session ID 가 화면에 문자열로 나오는가 (숫자로 오면 차단됩니다)
- [·] 판정 대기 중에 새 기록이 막히는가
- [·] 판정 대기 표시가 조작 화면에서도 보이는가

## 4.5 영상 (FR-20)

- [·] MJPEG 가 나오는가
- [·] 손 검출·신뢰도 표시가 영상 안에 겹쳐 나오는가
- [·] **WebSocket 을 끊었을 때** 영상은 유지되고 검출 표시가 "마지막 값" 으로 바뀌는가

---

# 5. 알려진 지뢰

- [·] **탭 두 개를 열지 마십시오** (D-1 해결 전)
      둘 다 제어권 보유로 인식하고, 한쪽 STOP 이 다른 쪽 제어를 끊습니다. 시연 중 실수하기 쉽습니다.

- [·] **`speed_limit` 이 최대속도 비율입니다**
      B-1 회신 전에는 실물 파지 시험을 하지 마십시오.

- [·] **landmark 파생 필드가 없으면 재검출 진행률이 안 나옵니다**
      `hand_loss_latched`·`reacquire_*` 는 선택 필드입니다. 없으면 웹이 150ms 로 근사하고 진행률 바를 감춥니다. Must 요건(자동 재개 안 됨 고지)은 충족됩니다.

- [·] **`FR-35` 타이밍 숫자는 웹의 사본입니다**
      YAML 을 바꾸면 화면이 거짓말합니다. A-3 이 "가능" 이면 사본 14개가 사라집니다.

---

# 6. 통합 중 상시

- [·] 문제가 생기면 **콘솔 `__diag()`** 를 복사해 공유
      담당·횟수·증상·조치·근거·실제값이 나옵니다. 담당별 이슈 목록이 됩니다.
- [·] "이 숫자 근거가 뭐냐" 는 **`__pending()`** 으로 답
- [ ] 회신이 오면 `pending.js` 의 키를 고치고 **출처를 같은 자리에 기록**
      ```js
      BRIDGE_SNAPSHOT_PERIOD_MS: 100,
      // status  확정
      // 회신    브릿지 담당 / 2026-08-__
      // 원문    "10Hz 고정 주기 발행"
      ```

---

# 7. 통합 후

- [ ] `pending.js` 에서 확정된 항목의 status 정리
- [ ] `CONTRACT_ASSUMPTIONS` 에서 확인된 항목 삭제 (현재 C-2·C-5·C-7·C-8)
- [ ] `interfaces-bridge.md` 3장의 결정 사항을 1장으로 이동
- [ ] `bridgeContract.test.jsx` 에 통합에서 실제로 만난 실패를 회귀로 추가
- [ ] NFR-22 이벤트 로그 (미뤘다면)
- [ ] FR-24 의 MediaPipe·hand_target·MJPEG 개별 상태 — NFR-09 가 diagnostics 소관으로 정리했으므로 하지 않아도 됩니다

---

# 회신 대기 목록

`docs/pending-decisions.md` 에 상세가 있습니다.

| | 담당 | 없으면 |
|---|---|---|
| A-1 snapshot 주기 | 브릿지 | 자동 측정으로 대체 가능 |
| A-2 ack 상한 | 브릿지 | 2초 가정. 잠금이 먼저 풀릴 수 있음 |
| A-3 FR-35 타이밍 동봉 | 브릿지 | 사본 14개 유지 |
| A-4 `sequence_running` 범위 | 브릿지 | 표시 문구만 부정확 |
| **B-1 `speed_limit`** | 제어·기구 | **실물 시험 불가** |
| C-1 `label` | 기획 | 빈 문자열 유지 |
| D-1 동시 접속 | 스펙 | 탭 하나만 열기 |
| E-1 거부 사유 전달 방식 | 브릿지 | 웹이 8종 추가하면 대부분 해결 |
| E-2 STOP 뒤 재획득 | 브릿지 | 눌러 보고 거부되면 안내 |

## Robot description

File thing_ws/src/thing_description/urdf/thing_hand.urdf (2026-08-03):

<?xml version='1.0' encoding='utf-8'?>
<robot name="thing_v521_right_hand">
  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
  <link name="palm">
    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
    <inertial>
      <origin xyz="-0.000861424371 -0.0320132375 0.00404745946" rpy="0 0 0" />
      <mass value="0.0633711649" />
      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
    </inertial>
  </link>
  <link name="index_proximal">
    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
    <inertial>
      <origin xyz="0.00286907842 -0.0220176391 0.00519369403" rpy="0 0 0" />
      <mass value="0.00530351948" />
      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
    </inertial>
  </link>
  <link name="index_middle">
    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
    <inertial>
      <origin xyz="0.001376434 -0.0137919001 0.00404679775" rpy="0 0 0" />
      <mass value="0.00303901191" />
      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
    </inertial>
  </link>
  <link name="index_distal">
    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
    <inertial>
      <origin xyz="0.000743478013 -0.00745836599 0.00326663442" rpy="0 0 0" />
      <mass value="0.00131384119" />
      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
    </inertial>
  </link>
  <link name="middle_proximal">
    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
    <inertial>
      <origin xyz="0.000848444237 -0.0242247023 0.00569596235" rpy="0 0 0" />
      <mass value="0.00626950747" />
      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
    </inertial>
  </link>
  <link name="middle_middle">
    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
    <inertial>
      <origin xyz="0.00035207055 -0.0169702396 0.00403875578" rpy="0 0 0" />
      <mass value="0.00352463342" />
      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
    </inertial>
  </link>
  <link name="middle_distal">
    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
    <inertial>
      <origin xyz="0.000196552908 -0.00760864001 0.00298660388" rpy="0 0 0" />
      <mass value="0.00137654563" />
      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
    </inertial>
  </link>
  <link name="ring_proximal">
    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
    <inertial>
      <origin xyz="-0.00162283087 -0.0240386985 0.00346108456" rpy="0 0 0" />
      <mass value="0.0052638291" />
      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
    </inertial>
  </link>
  <link name="ring_middle">
    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
    <inertial>
      <origin xyz="-0.000904382032 -0.0156486165 0.00319530349" rpy="0 0 0" />
      <mass value="0.00315108212" />
      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
    </inertial>
  </link>
  <link name="ring_distal">
    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
    <inertial>
      <origin xyz="-0.000381318037 -0.00822851527 0.00290161907" rpy="0 0 0" />
      <mass value="0.00137000323" />
      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
    </inertial>
  </link>
  <link name="little_proximal">
    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
    <inertial>
      <origin xyz="-0.00227236445 -0.0197994802 0.000979202217" rpy="0 0 0" />
      <mass value="0.0041505817" />
      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
    </inertial>
  </link>
  <link name="little_middle">
    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
    <inertial>
      <origin xyz="-0.00100527389 -0.0121103376 0.00286527583" rpy="0 0 0" />
      <mass value="0.00252154375" />
      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
    </inertial>
  </link>
  <link name="little_distal">
    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
    <inertial>
      <origin xyz="-0.000632471638 -0.00725024147 0.00231778435" rpy="0 0 0" />
      <mass value="0.00120513035" />
      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
    </inertial>
  </link>
  <link name="thumb_cmc_yoke">
    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
    <inertial>
      <origin xyz="0.00461393036 -0.00566590484 -0.00299509498" rpy="0 0 0" />
      <mass value="0.00235232204" />
      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
    </inertial>
  </link>
  <link name="thumb_metacarpal">
    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
    <inertial>
      <origin xyz="0.00587646151 -0.0118409134 -0.00444047805" rpy="0 0 0" />
      <mass value="0.00429243659" />
      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
    </inertial>
  </link>
  <link name="thumb_proximal">
    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
    <inertial>
      <origin xyz="0.00904758461 -0.0155967427 -0.00595423812" rpy="0 0 0" />
      <mass value="0.00488551678" />
      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
    </inertial>
  </link>
  <link name="thumb_distal">
    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
    <inertial>
      <origin xyz="0.00465134438 -0.00787351746 -0.00305718835" rpy="0 0 0" />
      <mass value="0.00182430044" />
      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
    </inertial>
  </link>
  <joint name="index_mcp" type="revolute">
    <parent link="palm" />
    <child link="index_proximal" />
    <origin xyz="0.0228000004 -0.0911600068 0.0102000013" rpy="0.0519738495 0.00634873472 0.000165021775" />
    <axis xyz="0.992615104 0.121306598 0" />
    <limit lower="-0.0523598776" upper="1.48352986" effort="1.0" velocity="2.0" />
    <dynamics damping="0.02" friction="0.0" />
  </joint>
  <joint name="index_pip" type="revolute">
    <parent link="index_proximal" />
    <child link="index_middle" />
    <origin xyz="0.00529307686 -0.0433116183 0.00639504753" rpy="0.0694609061 0.00701078726 0.00024358675" />
    <axis xyz="0.994936824 0.100502796 0" />
    <limit lower="-0.0698131701" upper="1.76278254" effort="1.0" velocity="2.0" />
    <dynamics damping="0.02" friction="0.0" />
  </joint>
  <joint name="index_dip" type="revolute">
    <parent link="index_middle" />
    <child link="index_distal" />
    <origin xyz="0.00259997323 -0.0257386863 0.00259997509" rpy="0.0347300246 0.00350750866 6.09141207e-05" />
    <axis xyz="0.994936824 0.100502796 0" />
    <limit lower="-0.034906585" upper="1.27409035" effort="1.0" velocity="2.0" />
    <dynamics damping="0.02" friction="0.0" />
  </joint>
  <joint name="middle_mcp" type="revolute">
    <parent link="palm" />
    <child link="middle_proximal" />
    <origin xyz="0 -0.0908000022 0.0108000003" rpy="0.0348955169 0.000880912296 1.53715046e-05" />
    <axis xyz="0.999681413 0.0252413992 0" />
    <limit lower="-0.034906585" upper="1.53588974" effort="1.0" velocity="2.0" />
    <dynamics damping="0.02" friction="0.0" />
  </joint>
  <joint name="middle_pip" type="revolute">
    <parent link="middle_proximal" />
    <child link="middle_middle" />
    <origin xyz="0.00122998923 -0.0487135798 0.00679074042" rpy="0.0523492955 0.0010505449 2.7503922e-05" />
    <axis xyz="0.999798596 0.0200731028 0" />
    <limit lower="-0.0523598776" upper="1.78023584" effort="1.0" velocity="2.0" />
    <dynamics damping="0.02" friction="0.0" />
  </joint>
  <joint name="middle_dip" type="revolute">
    <parent link="middle_middle" />
    <child link="middle_distal" />
    <origin xyz="0.000643215142 -0.0320371538 0.00273366459" rpy="0.0348995961 0.000700542587 1.22255678e-05" />
    <axis xyz="0.999798596 0.0200731028 0" />
    <limit lower="-0.034906585" upper="1.27409035" effort="1.0" velocity="2.0" />
    <dynamics damping="0.02" friction="0.0" />
  </joint>
  <joint name="ring_mcp" type="revolute">
    <parent link="palm" />
    <child link="ring_proximal" />
    <origin xyz="-0.0210000016 -0.0892399997 0.00420000032" rpy="0.069687359 -0.00419431087 -0.000146204562" />
    <axis xyz="0.998190701 -0.0601277016 0" />
    <limit lower="-0.0698131701" upper="1.50098316" effort="1.0" velocity="2.0" />
    <dynamics damping="0.02" friction="0.0" />
  </joint>
  <joint name="ring_pip" type="revolute">
    <parent link="ring_proximal" />
    <child link="ring_middle" />
    <origin xyz="-0.00282242335 -0.0468555987 0.00305762608" rpy="0.0871577188 -0.00436045136 -0.000190144172" />
    <axis xyz="0.998747706 -0.0500303991 0" />
    <limit lower="-0.0872664626" upper="1.74532925" effort="1.0" velocity="2.0" />
    <dynamics damping="0.02" friction="0.0" />
  </joint>
  <joint name="ring_dip" type="revolute">
    <parent link="ring_middle" />
    <child link="ring_distal" />
    <origin xyz="-0.00145199336 -0.028985858 0.00101639517" rpy="0.0522943735 -0.0026183899 -6.84791739e-05" />
    <axis xyz="0.998747706 -0.0500303991 0" />
    <limit lower="-0.0523598776" upper="1.25663706" effort="1.0" velocity="2.0" />
    <dynamics damping="0.02" friction="0.0" />
  </joint>
  <joint name="little_mcp" type="revolute">
    <parent link="palm" />
    <child link="little_proximal" />
    <origin xyz="-0.0402000025 -0.0795200095 -0.00540000014" rpy="0.104196586 -0.0104751913 -0.000546238676" />
    <axis xyz="0.994966209 -0.100211814 0" />
    <limit lower="-0.104719755" upper="1.43116999" effort="1.0" velocity="2.0" />
    <dynamics damping="0.02" friction="0.0" />
  </joint>
  <joint name="little_pip" type="revolute">
    <parent link="little_proximal" />
    <child link="little_middle" />
    <origin xyz="-0.00377025083 -0.037433438 -0.00188458757" rpy="0.139127553 -0.0118286312 -0.000824183691" />
    <axis xyz="0.996381819 -0.0849903002 0" />
    <limit lower="-0.13962634" upper="1.60570291" effort="1.0" velocity="2.0" />
    <dynamics damping="0.02" friction="0.0" />
  </joint>
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

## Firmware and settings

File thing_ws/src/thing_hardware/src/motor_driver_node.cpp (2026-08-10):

#include <algorithm>
#include <array>
#include <atomic>
#include <chrono>
#include <cmath>
#include <cstdint>
#include <limits>
#include <map>
#include <memory>
#include <mutex>
#include <set>
#include <stdexcept>
#include <string>
#include <utility>
#include <vector>

#include "diagnostic_msgs/msg/diagnostic_array.hpp"
#include "diagnostic_msgs/msg/diagnostic_status.hpp"
#include "diagnostic_msgs/msg/key_value.hpp"
#include "rclcpp/rclcpp.hpp"
#include "thing_hardware/dynamixel_bus.hpp"
#include "thing_hardware/thumb_motion_controller.hpp"
#include "thing_hardware/xl330_control_table.hpp"
#include "thing_interfaces/msg/hand_command.hpp"
#include "thing_interfaces/msg/motor_state.hpp"
#include "thing_interfaces/msg/motor_status.hpp"
#include "thing_interfaces/msg/safety_state.hpp"

namespace thing_hardware
{

namespace
{
constexpr double TWO_PI = 6.28318530717958647692;
constexpr double POSITION_RADIAN_UNIT = TWO_PI / 4096.0;
constexpr double RPM_TO_RADIAN_PER_SECOND = TWO_PI / 60.0;
constexpr int64_t SLOW_OPERATION_THRESHOLD_MS = 300;

template <typename ValueT>
ValueT clamp(ValueT value, ValueT minimum, ValueT maximum)
{
  return std::max(minimum, std::min(value, maximum));
}
}  // namespace

struct AxisConfig
{
  uint8_t motor_id;
  std::string actuator_name;
  std::size_t bus_index;
  bool control_enabled;
  int32_t home_position;
  int32_t closed_position;
  int32_t safe_position;
  int32_t position_tolerance;
  uint16_t position_p_gain;
  uint16_t position_i_gain;
  uint16_t position_d_gain;
  uint16_t goal_current;
  uint32_t profile_acceleration;
  uint32_t profile_velocity;
};

struct BusRuntime
{
  std::string name;
  std::string device;
  std::unique_ptr<DynamixelBus> driver;
  bool initialized{false};
  uint32_t failed_read_count{0};
  std::string last_error;
};

class MotorDriverNode : public rclcpp::Node
{
public:
  MotorDriverNode()
  : Node("motor_driver_node"), last_command_time_(std::chrono::steady_clock::now())
  {
    load_parameters();
    initialize_hardware();

    status_publisher_ = create_publisher<thing_interfaces::msg::MotorStatus>(
      "/thing/motor_status", rclcpp::QoS(rclcpp::KeepLast(5)).reliable());
    diagnostic_publisher_ = create_publisher<diagnostic_msgs::msg::DiagnosticArray>(
      "/thing/diagnostics", rclcpp::QoS(rclcpp::KeepLast(10)).reliable());
    command_subscription_ = create_subscription<thing_interfaces::msg::HandCommand>(
      "/thing/command", rclcpp::QoS(rclcpp::KeepLast(1)).reliable(),
      [this](thing_interfaces::msg::HandCommand::ConstSharedPtr message) {
        receive_command(*message);
      });
    safety_subscription_ = create_subscription<thing_interfaces::msg::SafetyState>(
      "/thing/safety_state", rclcpp::QoS(rclcpp::KeepLast(1)).reliable().transient_local(),
      [this](thing_interfaces::msg::SafetyState::ConstSharedPtr message) {
        receive_safety_state(*message);
      });

    read_timer_ = create_wall_timer(read_period_, [this]() { publish_motor_status(); });
    write_timer_ = create_wall_timer(write_period_, [this]() { run_control_cycle(); });
    diagnostic_timer_ = create_wall_timer(diagnostic_period_, [this]() { publish_diagnostics(); });

    RCLCPP_WARN(
      get_logger(),
      "Motor driver started in %s mode: motors=%zu, buses=%zu, thumb_control=%s, read=%.1f Hz, "
      "write=%.1f Hz",
      integration_test_mode_ ? "four-finger integration test" : "production", axes_.size(),
      buses_.size(), thumb_control_enabled_ ? "enabled" : "disabled", read_rate_hz_,
      write_rate_hz_);
  }

  ~MotorDriverNode() override { disable_torque(); }

private:
  template <typename ValueT>
  std::vector<ValueT> declare_integer_array(const std::string & name)
  {
    const auto values = declare_parameter<std::vector<int64_t>>(name, std::vector<int64_t>{});
    std::vector<ValueT> converted;
    converted.reserve(values.size());
    for (const int64_t value : values) {
      converted.push_back(static_cast<ValueT>(value));
    }
    return converted;
  }

  std::vector<double> declare_double_array(const std::string & name)
  {
    return declare_parameter<std::vector<double>>(name, std::vector<double>{});
  }

  void load_parameters()
  {
    integration_test_mode_ = declare_parameter<bool>("integration_test_mode", false);
    const int64_t baud_rate = declare_parameter<int64_t>("baud_rate", 57600);
    const double protocol_version = declare_parameter<double>("protocol_version", 2.0);
    operating_mode_ = declare_parameter<int>("operating_mode", 5);
    read_rate_hz_ = declare_parameter<double>("read_rate_hz", 20.0);
    write_rate_hz_ = declare_parameter<double>("write_rate_hz", 50.0);
    safe_velocity_limit_ = declare_parameter<double>("safe_velocity_limit", 0.5);
    safe_motion_timeout_seconds_ = declare_parameter<double>("safe_motion_timeout_seconds", 2.5);
    const double diagnostic_rate_hz = declare_parameter<double>("diagnostic_rate_hz", 1.0);
    hardware_command_watchdog_ms_ = declare_parameter<int>("hardware_command_watchdog_ms", 500);

    const auto bus_names =
      declare_parameter<std::vector<std::string>>("bus_names", std::vector<std::string>{});
    const auto bus_devices =
      declare_parameter<std::vector<std::string>>("bus_devices", std::vector<std::string>{});
    const auto motor_ids = declare_integer_array<int64_t>("motor_ids");
    const auto controlled_motor_ids = declare_integer_array<int64_t>("controlled_motor_ids");
    const auto actuator_names =
      declare_parameter<std::vector<std::string>>("actuator_names", std::vector<std::string>{});
    const auto bus_indices = declare_integer_array<int64_t>("bus_indices");
    const auto home_positions = declare_integer_array<int32_t>("home_positions_raw");
    const auto closed_positions = declare_integer_array<int32_t>("closed_positions_raw");
    const auto safe_positions = declare_integer_array<int32_t>("safe_positions_raw");
    const auto position_tolerances = declare_integer_array<int32_t>("position_tolerances_raw");
    const auto position_p_gains = declare_integer_array<uint16_t>("position_p_gains");
    const auto position_i_gains = declare_integer_array<uint16_t>("position_i_gains");
    const auto position_d_gains = declare_integer_array<uint16_t>("position_d_gains");
    const auto goal_currents = declare_integer_array<uint16_t>("goal_currents_ma");
    const auto profile_accelerations = declare_integer_array<uint32_t>("profile_accelerations_raw");
    const auto profile_velocities = declare_integer_array<uint32_t>("profile_velocities_raw");

    const auto thumb_pose_names = declare_parameter<std::vector<std::string>>(
      "thumb_functional_pose_names", std::vector<std::string>{});
    const auto thumb_opposition = declare_double_array("thumb_functional_opposition");
    const auto thumb_abduction = declare_double_array("thumb_functional_abduction");
    const auto thumb_opposition_positions =
      declare_integer_array<int32_t>("thumb_opposition_positions_raw");
    const auto thumb_opposition_directions =
      declare_integer_array<int8_t>("thumb_opposition_approach_directions");
    const auto thumb_opposition_starts =
      declare_integer_array<int32_t>("thumb_opposition_approach_start_positions_raw");
    const auto thumb_abduction_positions =
      declare_integer_array<int32_t>("thumb_abduction_positions_raw");
    const auto thumb_abduction_directions =
      declare_integer_array<int8_t>("thumb_abduction_approach_directions");
    const auto thumb_abduction_starts =
      declare_integer_array<int32_t>("thumb_abduction_approach_start_positions_raw");
    const auto thumb_flex_homes = declare_integer_array<int32_t>("thumb_flex_home_positions_raw");
    const auto thumb_flex_closed =
      declare_integer_array<int32_t>("thumb_flex_closed_positions_raw");
    const auto thumb_opposition_reversals =
      declare_integer_array<int32_t>("thumb_opposition_reversal_positions_raw");
    const auto thumb_abduction_reversals =
      declare_integer_array<int32_t>("thumb_abduction_reversal_positions_raw");
    const int32_t thumb_flex_clearance =
      declare_parameter<int>("thumb_flex_clearance_position_raw", 3200);
    const int32_t thumb_position_tolerance =
      declare_parameter<int>("thumb_position_tolerance_raw", 50);
    const int32_t thumb_approach_tolerance =
      declare_parameter<int>("thumb_approach_tolerance_raw", 75);
    const double thumb_motion_timeout =
      declare_parameter<double>("thumb_motion_timeout_seconds", 6.0);
    thumb_pose_switch_margin_ = declare_parameter<double>("thumb_pose_switch_margin", 0.1);
    thumb_pose_stable_samples_ = declare_parameter<int>("thumb_pose_stable_samples", 3);

    if (baud_rate <= 0 || protocol_version <= 0.0 || operating_mode_ < 0 || operating_mode_ > 16) {
      throw std::invalid_argument("invalid DYNAMIXEL communication or operating mode parameter");
    }
    if (
      read_rate_hz_ <= 0.0 || write_rate_hz_ <= 0.0 || diagnostic_rate_hz <= 0.0 ||
      hardware_command_watchdog_ms_ <= 0) {
      throw std::invalid_argument("rates and hardware watchdog must be positive");
    }
    if (
      safe_velocity_limit_ <= 0.0 || safe_velocity_limit_ > 1.0 ||
      safe_motion_timeout_seconds_ <= 0.0 || safe_motion_timeout_seconds_ > 3.0) {
      throw std::invalid_argument(
        "safe_velocity_limit must be in (0.0, 1.0] and "
        "safe_motion_timeout_seconds must be in (0.0, 3.0]");
    }
    if (bus_names.empty() || bus_names.size() != bus_devices.size()) {
      throw std::invalid_argument("bus_names and bus_devices must have the same non-zero size");
    }

    const std::size_t axis_count = motor_ids.size();
    const std::vector<std::size_t> sizes = {
      actuator_names.size(),   bus_indices.size(),           home_positions.size(),
      closed_positions.size(), safe_positions.size(),        position_tolerances.size(),
      position_p_gains.size(), position_i_gains.size(),      position_d_gains.size(),
      goal_currents.size(),    profile_accelerations.size(), profile_velocities.size()};
    if (axis_count == 0 || std::any_of(sizes.begin(), sizes.end(), [axis_count](std::size_t size) {
          return size != axis_count;
        })) {
      throw std::invalid_argument("all axis parameter arrays must have the same non-zero size");
    }
    if (axis_count != 7) {
      throw std::invalid_argument("motor status requires exactly seven configured motors");
    }

    std::set<int64_t> controlled_ids;
    for (const int64_t motor_id : controlled_motor_ids) {
      if (motor_id < 0 || motor_id > 252 || !controlled_ids.insert(motor_id).second) {
        throw std::invalid_argument(
          "controlled_motor_ids must contain unique values from 0 through 252");
      }
    }
    if (controlled_ids.empty()) {
      throw std::invalid_argument("controlled_motor_ids must not be empty");
    }

    buses_.reserve(bus_names.size());
    for (std::size_t index = 0; index < bus_names.size(); ++index) {
      if (bus_names[index].empty() || bus_devices[index].empty()) {
        throw std::invalid_argument("bus name and device must not be empty");
      }
      buses_.push_back(
        {bus_names[index], bus_devices[index],
         std::make_unique<DynamixelBus>(
           bus_devices[index], static_cast<int>(baud_rate), static_cast<float>(protocol_version)),
         false, 0, ""});
    }

    std::set<int64_t> unique_ids;
    std::set<std::string> unique_names;
    axes_.reserve(axis_count);
    for (std::size_t index = 0; index < axis_count; ++index) {
      if (
        motor_ids[index] < 0 || motor_ids[index] > 252 ||
        !unique_ids.insert(motor_ids[index]).second) {
        throw std::invalid_argument("motor IDs must be unique values from 0 through 252");
      }
      if (actuator_names[index].empty() || !unique_names.insert(actuator_names[index]).second) {
        throw std::invalid_argument("actuator names must be non-empty and unique");
      }
      if (bus_indices[index] < 0 || static_cast<std::size_t>(bus_indices[index]) >= buses_.size()) {
        throw std::invalid_argument("bus index is outside the configured bus list");
      }
      const bool control_enabled = controlled_ids.count(motor_ids[index]) != 0;
      if (
        control_enabled &&
        (home_positions[index] == closed_positions[index] || position_tolerances[index] < 0)) {
        throw std::invalid_argument(
          "controlled axis endpoints must differ and tolerance must be non-negative");
      }

      axes_.push_back(
        {static_cast<uint8_t>(motor_ids[index]), actuator_names[index],
         static_cast<std::size_t>(bus_indices[index]), control_enabled, home_positions[index],
         closed_positions[index], safe_positions[index], position_tolerances[index],
         position_p_gains[index], position_i_gains[index], position_d_gains[index],
         goal_currents[index], profile_accelerations[index], profile_velocities[index]});
    }
    std::sort(axes_.begin(), axes_.end(), [](const AxisConfig & left, const AxisConfig & right) {
      return left.motor_id < right.motor_id;
    });
    for (const int64_t controlled_id : controlled_ids) {
      if (unique_ids.count(controlled_id) == 0) {
        throw std::invalid_argument("controlled_motor_ids contains an unconfigured motor ID");
      }
    }

    thumb_flex_index_ = axis_index("thumb_flex");
    thumb_abduction_index_ = axis_index("thumb_abduction");
    thumb_opposition_index_ = axis_index("thumb_opposition");
    thumb_control_enabled_ = axes_[thumb_flex_index_].control_enabled &&
                             axes_[thumb_abduction_index_].control_enabled &&
                             axes_[thumb_opposition_index_].control_enabled;

    const std::size_t thumb_pose_count = thumb_pose_names.size();
    const std::vector<std::size_t> thumb_pose_sizes = {
      thumb_opposition.size(),           thumb_abduction.size(),
      thumb_opposition_positions.size(), thumb_opposition_directions.size(),
      thumb_opposition_starts.size(),    thumb_abduction_positions.size(),
      thumb_abduction_directions.size(), thumb_abduction_starts.size(),
      thumb_flex_homes.size(),           thumb_flex_closed.size()};
    if (
      thumb_control_enabled_ &&
      (thumb_pose_count == 0 ||
       std::any_of(
         thumb_pose_sizes.begin(), thumb_pose_sizes.end(),
         [thumb_pose_count](std::size_t size) { return size != thumb_pose_count; }) ||
       thumb_opposition_reversals.size() != thumb_pose_count * thumb_pose_count ||
       thumb_abduction_reversals.size() != thumb_pose_count * thumb_pose_count)) {
      throw std::invalid_argument("thumb functional-pose parameter arrays have invalid sizes");
    }
    if (
      thumb_pose_switch_margin_ < 0.0 || thumb_pose_stable_samples_ <= 0 ||
      thumb_motion_timeout <= 0.0) {
      throw std::invalid_argument("thumb motion parameters are invalid");
    }

    thumb_poses_.reserve(thumb_pose_count);
    for (std::size_t index = 0; index < thumb_pose_count; ++index) {
      if (
        thumb_pose_names[index].empty() || thumb_opposition[index] < 0.0 ||
        thumb_opposition[index] > 1.0 || thumb_abduction[index] < 0.0 ||
        thumb_abduction[index] > 1.0 ||
        std::abs(static_cast<int>(thumb_opposition_directions[index])) != 1 ||
        std::abs(static_cast<int>(thumb_abduction_directions[index])) != 1) {
        throw std::invalid_argument("thumb functional pose contains an invalid value");
      }
      thumb_poses_.push_back(
        {thumb_pose_names[index], thumb_opposition[index], thumb_abduction[index],
         thumb_opposition_positions[index], thumb_opposition_directions[index],
         thumb_opposition_starts[index], thumb_abduction_positions[index],
         thumb_abduction_directions[index], thumb_abduction_starts[index], thumb_flex_homes[index],
         thumb_flex_closed[index]});
    }
    if (thumb_control_enabled_) {
      thumb_controller_ = std::make_unique<ThumbMotionController>(
        thumb_poses_, thumb_position_tolerance, thumb_approach_tolerance,
        std::chrono::duration<double>(thumb_motion_timeout), thumb_flex_clearance,
        thumb_opposition_reversals, thumb_abduction_reversals);
    }

    read_period_ = std::chrono::duration_cast<std::chrono::nanoseconds>(
      std::chrono::duration<double>(1.0 / read_rate_hz_));
    write_period_ = std::chrono::duration_cast<std::chrono::nanoseconds>(
      std::chrono::duration<double>(1.0 / write_rate_hz_));
    diagnostic_period_ = std::chrono::duration_cast<std::chrono::nanoseconds>(
      std::chrono::duration<double>(1.0 / diagnostic_rate_hz));
    commanded_positions_.resize(axes_.size());
    desired_positions_.resize(axes_.size());
    latest_present_positions_.resize(axes_.size());
    latest_goal_positions_.resize(axes_.size());
    latest_present_currents_ampere_.resize(axes_.size());
    latest_torque_enabled_.resize(axes_.size());
    latest_position_valid_.resize(axes_.size(), false);
  }

  std::size_t axis_index(const std::string & name) const
  {
    const auto iterator = std::find_if(axes_.begin(), axes_.end(), [&name](const auto & axis) {
      return axis.actuator_name == name;
    });
    if (iterator == axes_.end()) {
      throw std::invalid_argument("required actuator is missing: " + name);
    }
    return static_cast<std::size_t>(std::distance(axes_.begin(), iterator));
  }

  void require_write(const DriverResult & result, const std::string & operation)
  {
    if (!result.success) {
      throw std::runtime_error(operation + ": " + result.error_message);
    }
  }

  void initialize_hardware()
  {
    for (auto & bus : buses_) {
      const DriverResult result = bus.driver->initialize();
      bus.initialized = result.success;
      bus.last_error = result.error_message;
      if (!result.success) {
        throw std::runtime_error("failed to initialize " + bus.name + ": " + result.error_message);
      }
      RCLCPP_INFO(
        get_logger(), "DYNAMIXEL bus initialized: %s (%s)", bus.name.c_str(), bus.device.c_str());
    }

    for (const auto & axis : axes_) {
      auto & driver = *buses_[axis.bus_index].driver;
      uint16_t model_number = 0;
      require_write(
        driver.ping(axis.motor_id, model_number),
        "failed to ping ID=" + std::to_string(axis.motor_id));
      if (model_number != xl330::EXPECTED_MODEL_NUMBER) {
        throw std::runtime_error(
          "unexpected model number for ID=" + std::to_string(axis.motor_id) +
          ": expected=" + std::to_string(xl330::EXPECTED_MODEL_NUMBER) +
          ", actual=" + std::to_string(model_number));
      }
      require_write(
        driver.write_one_byte(axis.motor_id, xl330::TORQUE_ENABLE_ADDRESS, 0),
        "failed to disable torque for ID=" + std::to_string(axis.motor_id));
      if (!axis.control_enabled) {
        RCLCPP_INFO(
          get_logger(), "Motor monitored with torque disabled: ID=%u, axis=%s, model=%u",
          static_cast<unsigned int>(axis.motor_id), axis.actuator_name.c_str(),
          static_cast<unsigned int>(model_number));
        continue;
      }
      require_write(
        driver.write_one_byte(
          axis.motor_id, xl330::OPERATING_MODE_ADDRESS, static_cast<uint8_t>(operating_mode_)),
        "failed to set operating mode for ID=" + std::to_string(axis.motor_id));
      require_write(
        driver.write_two_bytes(axis.motor_id, xl330::POSITION_P_GAIN_ADDRESS, axis.position_p_gain),
        "failed to set P gain for ID=" + std::to_string(axis.motor_id));
      require_write(
        driver.write_two_bytes(axis.motor_id, xl330::POSITION_I_GAIN_ADDRESS, axis.position_i_gain),
        "failed to set I gain for ID=" + std::to_string(axis.motor_id));
      require_write(
        driver.write_two_bytes(axis.motor_id, xl330::POSITION_D_GAIN_ADDRESS, axis.position_d_gain),
        "failed to set D gain for ID=" + std::to_string(axis.motor_id));
      require_write(
        driver.write_two_bytes(axis.motor_id, xl330::GOAL_CURRENT_ADDRESS, axis.goal_current),
        "failed to set goal current for ID=" + std::to_string(axis.motor_id));
      require_write(
        driver.write_four_bytes(
          axis.motor_id, xl330::PROFILE_ACCELERATION_ADDRESS, axis.profile_acceleration),
        "failed to set profile acceleration for ID=" + std::to_string(axis.motor_id));
      require_write(
        driver.write_four_bytes(
          axis.motor_id, xl330::PROFILE_VELOCITY_ADDRESS, axis.profile_velocity),
        "failed to set profile velocity for ID=" + std::to_string(axis.motor_id));
      RCLCPP_INFO(
        get_logger(), "Motor configured: ID=%u, axis=%s, model=%u",
        static_cast<unsigned int>(axis.motor_id), axis.actuator_name.c_str(),
        static_cast<unsigned int>(model_number));
    }
  }

  double axis_command(const thing_interfaces::msg::HandCommand & command, const std::string & name)
  {
    if (name == "ring_flex") {
      return command.ring_flex;
    }
    if (name == "middle_flex") {
      return command.middle_flex;
    }
    if (name == "index_flex") {
      return command.index_flex;
    }
    if (name == "little_flex") {
      return command.little_flex;
    }
    if (name == "thumb_flex") {
      return command.thumb_flex;
    }
    if (name == "thumb_abduction") {
      return command.thumb_abd;
    }
    if (name == "thumb_opposition") {
      return command.thumb_opp;
    }
    throw std::invalid_argument("unsupported actuator name: " + name);
  }
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
int main(int argc, char * argv[])
{
  rclcpp::init(argc, argv);
  try {
    rclcpp::spin(std::make_shared<thing_hardware::MotorDriverNode>());
  } catch (const std::exception & exception) {
    RCLCPP_FATAL(rclcpp::get_logger("motor_driver_node"), "%s", exception.what());
  }
  rclcpp::shutdown();
  return 0;
}

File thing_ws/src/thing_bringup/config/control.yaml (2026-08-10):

estop_gpio_node:
  ros__parameters:
    # Tested Raspberry Pi wiring: isolated NO auxiliary contact to GND.
    # Released/open is HIGH; pressed/closed is LOW. The separate main NC
    # contact removes motor drive power independently of this GPIO process.
    gpio_chip: "gpiochip4"
    gpio_line: 17
    active_low: true
    poll_interval_ms: 5
    debounce_ms: 50
    heartbeat_period_ms: 100
    # Validated startup range: 1..500 ms; slower recovery is rejected.
    reopen_interval_ms: 500
    safety_timeout_ms: 300

command_manager:
  ros__parameters:
    owner_lease_timeout_ms: 3000
    stop_reacquire_delay_ms: 500
    lease_check_period_ms: 100
    state_publish_period_ms: 1000

manual_executor:
  ros__parameters:
    # At most 50 ms preserves the V7.0 requirement of fresh commands at >=20 Hz.
    publish_period_ms: 50
    control_state_timeout_ms: 1500
    safety_state_timeout_ms: 300

    # Normalized HandCommand order:
    # thumb_flex, thumb_opp, thumb_abd, index, middle, ring, little.
    # Tune these software presets after physical endpoint calibration; hardware
    # limits and Command Guard remain the final safety boundary.
    gestures.open.axes: [0.0, 0.0, 0.0, 0.0, 0.0, 0.0, 0.0]
    gestures.open.duration_ms: 1000
    # A normal fist uses the validated grasp thumb pose.
    gestures.fist.axes: [1.0, 0.6, 0.2, 1.0, 1.0, 1.0, 1.0]
    gestures.fist.duration_ms: 1000
    gestures.pinch.axes: [1.0, 0.6, 0.2, 1.0, 0.0, 0.0, 0.0]
    gestures.pinch.duration_ms: 3000
    gestures.cylindrical_grasp.axes: [0.8, 0.6, 0.2, 0.85, 0.85, 0.85, 0.85]
    gestures.cylindrical_grasp.duration_ms: 3000

    # Sequence-only presets. ExecuteGesture still accepts only the four
    # canonical gestures plus home|paper|rock aliases.
    # Countdown uses the folded thumb pose.
    gestures.count_4.axes: [1.0, 1.0, 1.0, 0.0, 0.0, 0.0, 0.0]
    gestures.count_3.axes: [1.0, 1.0, 1.0, 0.0, 0.0, 0.0, 1.0]
    gestures.scissors.axes: [1.0, 1.0, 1.0, 0.0, 0.0, 1.0, 1.0]
    gestures.count_1.axes: [1.0, 1.0, 1.0, 0.0, 1.0, 1.0, 1.0]

    sequences.countdown.steps: [open, count_4, count_3, scissors, count_1, fist, open]
    sequences.countdown.step_durations_ms: [3000, 3000, 3000, 3000, 3000, 3000, 3000]
    sequences.scissors_rock_paper.steps: [fist, open, scissors]
    sequences.scissors_rock_paper.step_durations_ms: [3000, 3000, 3000]

command_guard:
  ros__parameters:
    command_timeout_ms: 300
    command_hold_ms: 5000
    command_future_tolerance_ms: 100
    safety_state_timeout_ms: 1500
    control_state_timeout_ms: 1500
    diagnostic_period_ms: 1000
    axis_limits:
      thumb_flex:
        min: 0.0
        max: 1.0
        max_delta_per_second: 1.0
      thumb_opp:
        min: 0.0
        max: 1.0
        max_delta_per_second: 1.0
      thumb_abd:
        min: 0.0
        max: 1.0
        max_delta_per_second: 1.0
      index_flex:
        min: 0.0
        max: 1.0
        max_delta_per_second: 1.5
      middle_flex:
        min: 0.0
        max: 1.0
        max_delta_per_second: 1.5
      ring_flex:
        min: 0.0
        max: 1.0
        max_delta_per_second: 1.5
      little_flex:
        min: 0.0
        max: 1.0
        max_delta_per_second: 1.5
    # Vision keeps each landmark-frame change within 0.08 at up to 30 Hz.
    # At MIMIC speed_limit 0.25 this requires 9.6/s; 10.0/s includes rounding.
    # This profile applies only to SOURCE_MIMIC. Other sources use axis_limits.
    mimic_axis_limits:
      thumb_flex:
        max_delta_per_second: 10.0
      thumb_opp:
        max_delta_per_second: 10.0
      thumb_abd:
        max_delta_per_second: 10.0
      index_flex:
        max_delta_per_second: 10.0
      middle_flex:
        max_delta_per_second: 10.0
      ring_flex:
        max_delta_per_second: 10.0
      little_flex:
        max_delta_per_second: 10.0

safety_manager:
  ros__parameters:
    command_hold_ms: 5000
    command_safe_ms: 10000
    safe_action_timeout_ms: 3000
    recovery_stable_ms: 300
    recovery_max_gap_ms: 100
    reset_min_ms: 500
    reset_timeout_ms: 3000
    estop_release_ms: 500
    fault_clear_stable_ms: 1000
    hardware_status_timeout_ms: 300
    estop_input_timeout_ms: 300
    tick_period_ms: 20
    state_publish_period_ms: 100
    # ROBOTIS XL330-M288-T e-Manual: recommended 5.0 V stall current is 1.47 A.
    # V7 still requires project-specific physical load validation of this trip.
    trip_limits_validated: true
    max_current_ampere: 1.47
    max_temperature_celsius: 70.0

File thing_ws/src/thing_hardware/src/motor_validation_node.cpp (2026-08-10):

#include <chrono>
#include <cstdint>
#include <limits>
#include <memory>
#include <stdexcept>
#include <string>

#include "rclcpp/rclcpp.hpp"
#include "thing_hardware/dynamixel_bus.hpp"
#include "thing_hardware/xl330_control_table.hpp"

class MotorValidatorNode : public rclcpp::Node
{
public:
  MotorValidatorNode() : Node("motor_validator")
  {
    declare_parameters();
    load_and_validate_parameters();

    RCLCPP_INFO(
      this->get_logger(), "Device: %s, baud rate: %d, protocol: %.1f, motor ID: %u",
      device_name_.c_str(), baud_rate_, protocol_version_, static_cast<unsigned int>(motor_id_));

    // ==== bus initialize ====
    bus_ =
      std::make_unique<thing_hardware::DynamixelBus>(device_name_, baud_rate_, protocol_version_);

    const auto initialize_result = bus_->initialize();

    if (!initialize_result.success) {
      RCLCPP_ERROR(
        this->get_logger(), "Failed to initialize DYNAMIXEL bus: %s",
        initialize_result.error_message.c_str());
      return;
    }

    RCLCPP_INFO(this->get_logger(), "DYNAMIXEL bus initialized: %s", device_name_.c_str());
    // ========================

    // ==== ping check ====
    uint16_t model_number = 0;

    const auto ping_result = bus_->ping(motor_id_, model_number);

    if (!ping_result.success) {
      RCLCPP_ERROR(
        this->get_logger(), "Ping failed for ID %u: %s", static_cast<unsigned int>(motor_id_),
        ping_result.error_message.c_str());
      return;
    }

    RCLCPP_INFO(
      this->get_logger(), "Ping succeeded: ID=%u, model number=%u",
      static_cast<unsigned int>(motor_id_), static_cast<unsigned int>(model_number));

    if (model_number != thing_hardware::xl330::EXPECTED_MODEL_NUMBER) {
      RCLCPP_WARN(
        this->get_logger(), "Unexpected model: expected=%u, received=%u",
        static_cast<unsigned int>(thing_hardware::xl330::EXPECTED_MODEL_NUMBER),
        static_cast<unsigned int>(model_number));
    }
    // ====================

    // ==== drive mode read ====
    uint8_t drive_mode = 0;

    const auto drive_mode_result =
      bus_->read_one_byte(motor_id_, thing_hardware::xl330::DRIVE_MODE_ADDRESS, drive_mode);

    if (!drive_mode_result.success) {
      RCLCPP_ERROR(
        this->get_logger(), "Failed to read Drive Mode: %s",
        drive_mode_result.error_message.c_str());
      return;
    }

    RCLCPP_INFO(
      this->get_logger(), "Drive Mode: ID=%u, raw=0x%02X, torque_on_by_goal_update=%s",
      static_cast<unsigned int>(motor_id_), static_cast<unsigned int>(drive_mode),
      (drive_mode & 0x08U) == 0U ? "disabled" : "enabled");
    // =========================

    // ==== operating mode read ====
    uint8_t operating_mode = 0;

    const auto operating_mode_result =
      bus_->read_one_byte(motor_id_, thing_hardware::xl330::OPERATING_MODE_ADDRESS, operating_mode);

    if (!operating_mode_result.success) {
      RCLCPP_ERROR(
        this->get_logger(), "Failed to read Operating Mode: %s",
        operating_mode_result.error_message.c_str());
      return;
    }

    RCLCPP_INFO(
      this->get_logger(), "Operating Mode: ID=%u, raw=%u, value=%s",
      static_cast<unsigned int>(motor_id_), static_cast<unsigned int>(operating_mode),
      operating_mode_name(operating_mode));
    // =============================

    // ==== current limit read ====
    uint16_t raw_current_limit = 0;

    const auto current_limit_result = bus_->read_two_bytes(
      motor_id_, thing_hardware::xl330::CURRENT_LIMIT_ADDRESS, raw_current_limit);

    if (!current_limit_result.success) {
      RCLCPP_ERROR(
        this->get_logger(), "Failed to read Current Limit: %s",
        current_limit_result.error_message.c_str());
      return;
    }

    const double current_limit_ma =
      static_cast<double>(raw_current_limit) * thing_hardware::xl330::CURRENT_MILLIAMPERE_UNIT;

    RCLCPP_INFO(
      this->get_logger(), "Current Limit: ID=%u, raw=%u, value=%.1f mA",
      static_cast<unsigned int>(motor_id_), static_cast<unsigned int>(raw_current_limit),
      current_limit_ma);
    // ============================

    // ==== velocity limit read ====
    uint32_t raw_velocity_limit = 0;

    const auto velocity_limit_result = bus_->read_four_bytes(
      motor_id_, thing_hardware::xl330::VELOCITY_LIMIT_ADDRESS, raw_velocity_limit);

    if (!velocity_limit_result.success) {
      RCLCPP_ERROR(
        this->get_logger(), "Failed to read Velocity Limit: %s",
        velocity_limit_result.error_message.c_str());
      return;
    }

    const double velocity_limit_rpm =
      static_cast<double>(raw_velocity_limit) * thing_hardware::xl330::VELOCITY_RPM_UNIT;

    RCLCPP_INFO(
      this->get_logger(), "Velocity Limit: ID=%u, raw=%u, value=%.2f rpm",
      static_cast<unsigned int>(motor_id_), static_cast<unsigned int>(raw_velocity_limit),
      velocity_limit_rpm);
    // =============================

    // ==== maximum position limit read ====
    uint32_t raw_max_position_limit = 0;

    const auto max_position_limit_result = bus_->read_four_bytes(
      motor_id_, thing_hardware::xl330::MAX_POSITION_LIMIT_ADDRESS, raw_max_position_limit);

    if (!max_position_limit_result.success) {
      RCLCPP_ERROR(
        this->get_logger(), "Failed to read Max Position Limit: %s",
        max_position_limit_result.error_message.c_str());
      return;
    }

    const double max_position_limit_degrees =
      static_cast<double>(raw_max_position_limit) * thing_hardware::xl330::POSITION_DEGREE_UNIT;
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

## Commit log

2026-07-15 chore: initialize project structure
    [BOM.csv]
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2026-07-15 feat(mechanical): add V3 hand model and validation assets [S15P11C103-12]
    [Thing_V3.blend, Thing_V3_01_01_V3_PRINT_01_PALM_CORE.stl, Thing_V3_02_02_V3_PRINT_INDEX_PROXIMAL.stl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]
2026-07-27 chore(integration): align repository with requirements v5 [S15P11C103-113]
    [BOM.csv, motors.yaml]
2026-07-28 [S15P11C103-62] DYNAMIXEL 모터 제어 도구 및 spool 자료 추가
    [xl330_hnx330_n101_2mm_3turn_spool_v3_two_piece_7set_bambu_plate.3mf, xl330_hnx330_n101_2mm_3turn_spool_v3_two_piece_assembly.blend, xl330_hnx330_n101_2mm_3turn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]
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2026-07-29 S15P11C103-76 Safety Reset 서비스 및 인터페이스 문서 정리
    [safety_manager.py]
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2026-07-30 [S15P11C103-41] Thing V5.2.1 기구·로봇 모델 통합
    [Thing_V5_2_1_01_V521_PRINT_01_PALM_CORE.stl, Thing_V5_2_1_02_V521_PRINT_INDEX_PROXIMAL.stl, Thing_V5_2_1_03_V521_PRINT_INDEX_MIDDLE.stl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]
2026-07-30 [S15P11C103-120] EC2 웹 프로젝트 수정
2026-07-31 [S15P11C103-36][S15P11C103-37][S15P11C103-38] Raspberry Pi 모터 제어 스크립트 추가
    [motor_config.json]
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2026-07-31 feat(hardware): read DYNAMIXEL hardware error status [S15P11C103-64]
    [motor_validation_node.cpp]
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2026-07-31 config(hardware): record calibrated motor environment [S15P11C103-38]
    [motors.yaml]
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2026-08-03 test(hardware): reset integral gain for return motion [S15P11C103-64]
    [motor_validation_node.cpp]
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2026-08-03 feat(control): harden fail-closed safety control [S15P11C103-79]
    - implement deterministic RESET, HOLD recovery, and SAFE/FAULT/ESTOP transitions
    - enforce causal STOP closure, owner lease handling, freshness, and deadline boundaries
    - add least-privilege SROS2 policy, control launch gating, and regression coverage
    - synchronize control interfaces and safety documentation without changing docs/requirements
    Related Jira:
    - S15P11C103-77: https://ssafy.atlassian.net/browse/S15P11C103-77
    - S15P11C103-79: https://ssafy.atlassian.net/browse/S15P11C103-79
    - S15P11C103-102: https://ssafy.atlassian.net/browse/S15P11C103-102
    - S15P11C103-117: https://ssafy.atlassian.net/browse/S15P11C103-117
    - S15P1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
    [control.yaml, safety_manager.py, safety_manager_core.py]
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2026-08-03 feat(hardware): add thumb group calibration [S15P11C103-64]
    [thumb_calibration.yaml]
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2026-08-03 S15P11C103-124 fix: export 중 recording 차단 제거
    [export_worker.py, logger.py]
2026-08-03 S15P11C103-124 fix: CSV timestamp 비감소 검증 추가
    [exporter.py]
2026-08-03 docs(control): clarify control node behavior [S15P11C103-79]
    Document the runtime responsibilities, state transitions, timing boundaries, replay handling, and fail-closed behavior of Command Manager, Command Guard, and Safety Manager without changing executable logic.
    [safety_manager.py, safety_manager_core.py]
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2026-08-04 S15P11C103-124 fix: canonical export 결정론 및 검증 보강
    [export_schema.py, exporter.py]
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2026-08-04 feat(control): integrate manual gesture and sequence executor [S15P11C103-100]
    Unify Gesture service and Sequence action admission behind one MANUAL command publisher. Add fail-closed STOP barrier correlation, recovery gating, SROS2 policy, configuration, documentation, and regression coverage.
    [control.yaml, safety_manager.py]
2026-08-04 fix(control): extend safety watchdog grace periods [S15P11C103-100]
    Set the command watchdog to enter HOLD after 5 seconds and SAFE after 10 seconds. Keep the ROS defaults, core limits, bringup configuration, and regression tests aligned.
    [control.yaml, safety_manager.py, safety_manager_core.py]
2026-08-04 S15P11C103-91 feat: ROS 2↔WebSocket 브리지 서버 구현
    web_bridge_node가 /ws/robot-state에서 6개 top-level 필드 snapshot을
    발행하고 브라우저 요청을 검증된 ROS 2 서비스·액션으로만 변환한다.
    - protocol.py: snapshot 직렬화, enum 매핑, 요청 envelope 검증
    - websocket_server.py: ROS executor와 분리된 async 전송 계층
    - web_bridge_node.py: 6개 토픽 구독, 5 서비스 + 1 액션 + reset_safety
    - QoS를 명세 6.3절에 맞춤 (landmarks Best Effort, MotorStatus depth 5,
    Control/Safety/Recording Transient Local)
    - uint64 Session ID를 10진 문자열로 인코딩
    - vision.launch.py에 Jetson 5개 노드 포함 (FR-42)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
    [vision.yaml]
2026-08-04 S15P11C103-91 fix: NaN 크래시 제거와 hand-loss·연결 표시 상태 파생
    - 모터 읽기 실패로 NaN이 오면 ROS 구독 콜백에서 ProtocolError가 터져
    노드가 죽었다. 표시 경로는 JSON null로 변환한다 (NFR-06 고장 격리,
    6.5절 "읽기 실패 숫자는 null")
    - FR-27이 Web Bridge에 배정한 hand-loss latch를 HandLandmarks에서 파생한다.
    FR-01 기준 그대로 오른손·confidence>=0.70·미검출 150ms·재검출 300ms이며
    재검출만으로 latch를 해제하지 않고 SafetyState RUN에서만 닫는다
    - connection_status 5종과 섹션별 stale·age_ms를 파생한다 (FR-24, FR-25).
    아직 못 받음(unknown)과 끊김(down)을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
2026-08-04 S15P11C103-91 fix: STOP·Safety Reset이 일반 요청 대기열을 선점
    기존 구조는 요청 하나를 처리하는 동안 다음 메시지를 읽지 않아 STOP이
    긴급 요청인지 확인조차 못 하고 대기열 맨 뒤에서 기다렸다. 내부 제어 웹이
    1000ms마다 lease 갱신을 보내는데 ROS 호출이 그보다 느려지면 대기열이 무한히
    쌓여 STOP이 계속 밀린다. 측정 결과 STOP ack가 7초 밀리고 매초 1초씩 증가했다.
    FR-19·FR-31의 "STOP과 안전 전이는 일반 동작을 항상 선점한다"를 지키지 못한다.
    수신과 실행을 분리한다.
    - reader: ROS를 기다리지 않고 메시지를 계속 읽어 분류
    - worker: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
2026-08-05 S15P11C103-91 docs: WebSocket 계약 동결과 웹 회신 8건
    명세 6.4절이 "세 객체의 세부 field와 클라이언트→서버 요청 JSON은 통합 시험 전에
    docs/interfaces.md에 동결"하라고 요구하고, 8.3 최소 검수 조건 2번도 계약 반영을
    요구한다. 프론트엔드는 진단 메시지에서 web/docs/interfaces-bridge.md의 절 번호를
    가리키는데 파일이 없었다.
    docs/interfaces.md WebSocket 절 확장
    - 전송 규칙(주기·동시 연결·close code·상한)
    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
2026-08-05 S15P11C103-91 fix: timeout된 서비스 요청을 rclpy pending 목록에서 정리
    - _wait_future가 timeout으로 포기한 future를 Client의 pending
    목록에서 remove_pending_request로 함께 제거한다.
    - 응답이 영영 오지 않는 서비스(상대 프로세스 사망 등)에서 pending
    항목이 무한히 쌓이는 누수를 막는다.
2026-08-05 S15P11C103-91 test: 실제 인터페이스 대조와 재연결 무재실행 검증 추가
    - test_interface_contract.py 신규: protocol.py의 enum symbol 표를
    실제 thing_interfaces .msg 상수와 한 칸씩 대조하고, 브리지가 읽는
    필드가 .msg에 실제로 존재하는지와 7 msg·5 srv·1 action 유지를
    검증한다. 실제 메시지로 snapshot 직렬화(JSON, NaN→null)까지 확인.
    - test_websocket_server.py: 연결 해제 시 대기 중 요청이 폐기되고
    재연결이 이전 요청을 재실행하지 않음(0건, NFR-15)을 검증하는
    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
2026-08-05 S15P11C103-91 style: pep257 D213 계열 docstring 위반 10건 정리
    - 여러 줄 docstring의 요약을 둘째 줄로 옮겨 ament_pep257 D213을
    만족시킨다 (colcon test의 test_pep257이 HEAD에서 실패하던 문제).
    - _with_freshness_locked는 요약·본문 분리와 마침표 누락(D205·D209·
    D400·D415)까지 함께 고쳤다. 코드 동작 변경 없음.
2026-08-05 S15P11C103-91 fix: 구독 콜백 크래시 가드와 종료·검증 경로 보강
    코드 리뷰에서 찾은 견고성 문제 4건을 고친다.
    - 구독 콜백 크래시 가드: enum 범위 밖 값 등 버전 불일치 메시지가
    ProtocolError로 spin을 죽여 브리지 전체가 내려가던 것을 _guarded
    래퍼로 막는다. 해당 메시지만 버리고 5초 스로틀 warning을 남긴다
    (NaN 크래시 fdfcc34와 같은 계열의 남은 경로).
    - destroy_node: WebSocket stop() 실패(join timeout)가 action client와
    rclpy 자원 정리를 건너뛰게 하던 것을 try/except로 격리한다.
    - session_id 검증: '00'·'007' 같은 선행 0(센티널 0 오인)과 '²'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
2026-08-05 S15P11C103-91 fix: session_id 거부 이유를 계약 표대로 형식·값으로 구분
    완료조건 2번(각 허용·거부 요청과 이유가 구분된다)과 docs/interfaces.md
    ACK reason 표를 맞춘다. 기존에는 모든 session_id 거부가
    web_malformed_request로 나가 계약이 정의한 invalid_session_id가 요청
    경로에서는 한 번도 발행되지 않았다.
    - 형식 오류(비문자열·비ascii·비숫자·선행 0) -> web_malformed_request
    - 값 오류(0 또는 63-bit 초과) -> invalid_session_id
    - '0'은 0의 표준 표기이므로 값 사유, '00'·'007'은 표준 표기가 아니라
    형식 사유로 구분한다.
    test: 거부 이유를 직접 대조하는 pa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
2026-08-05 feat(bringup): add secure hand launch [S15P11C103-146]
    [motors.yaml]
2026-08-05 fix(bringup): preserve existing motor configuration [S15P11C103-146]
    [motors.yaml]
2026-08-05 S15P11C103-91 docs: 브리지 기동 절차와 websockets 최소 버전 명시
    websockets 9.1은 Python 3.10에서 제거된 loop 인자를 asyncio에 넘겨 접속
    즉시 끊긴다. bind와 기동 로그는 정상이라 로그만으로 원인을 찾기 어렵다.
    - package.xml: python3-websockets에 version_gte="10.0"
    - README: 버전 확인 명령과 구버전 호스트 pip 우회 방법
    - README: 기동·테스트 절차, vision.yaml 파라미터 기본값, 기동 확인 로그
    - README: 계약 문서 링크. 계약 본문은 중복 기재하지 않음
    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
2026-08-05 S15P11C103-91 test: 실제 WebSocket 클라이언트로 계약 E2E 검증 추가
    기존 테스트는 FakeWebSocket으로 ClientSession을 직접 호출해 handshake와
    close code, 실제 프레임 왕복을 확인하지 못했다. 진짜 websockets 클라이언트로
    붙어 계약을 wire에서 검증한다. 12건이며 완료조건 1·2·4번에 대응한다.
    - snapshot: 고정 6필드 순서, type 필드 없음, mode가 문자열, 미수신은 {},
    확장 필드 4종, connection_status 5키와 up/down/unknown
    - ACK: request_id 동일 반환, invalid_session_id와 web_malformed_request·
    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
2026-08-05 S15P11C103-91 fix: 개정된 6.4절 snapshot v1 계약에 맞춰 원문 절 분리
    6.4절이 top-level을 여섯에서 여덟 필드로 확정하고 control_state·recording의
    취급을 명시했다. 이전 구현이 세 곳에서 어긋나 바로잡는다.
    - SNAPSHOT_FIELDS를 여덟 필드로 확장한다. control_state·recording이 고정
    계약에 포함됐다.
    - control_state·recording을 원문 그대로 싣는다. enum symbol 변환을 제거해
    정수 상수가 그대로 나간다. 웹의 toSymbol·*_BY_ORDINAL이 이 두 절을 변환한다.
    - 세션 없음 표현을 빈 문자열에서 "0"으로 바꾼다. 6.4절이 "10진 문자열로
    직렬화하며 세션 없음은 '0'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
2026-08-05 feat(hardware): add fail-closed E-Stop GPIO input
    [control.yaml, estop_gpio_node.py, estop_input.py]
2026-08-05 S15P11C103-125 feat: 격리 uploader 데몬 구현
    logger와 별도 프로세스로 기동하는 소켓 서버. exporter가
    /run/thing-uploader/uploader.sock으로 넘긴 완료 4파일 manifest를 받아
    읽기 전용 재검증(파일 집합·symlink·경로 이탈·크기·SHA-256) 후
    EC2 업로드 API에 Bearer Token multipart POST 한 번으로 전송한다.
    - uploader_contract.py: manifest 파싱·ACK 직렬화·env 기반 Config·예외
    (uploader_handoff.py 클라이언트와 미러, 격리 위해 exporter 미참조)
    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
2026-08-05 S15P11C103-125 docs: logger·exporter·uploader Jetson 배치 확정 및 문서 동기화
    - 배치 결정문서 신규: P1 Jetson 배치, P2 uploader는 thing_logger 패키지 유지
    - landmark 합의문서의 uploader 위치를 실제 구현 경로로 정정
    - README·architecture.md 역할표에서 Logger·exporter·uploader를 Pi→Jetson 이동
    - setup/jetson.md: thing_logger 필수화 + 격리 uploader 데몬 명시
    - interfaces.md: logger 구독 목록 실구현 기준 정정(command/mimic·stop_requested 제거)
    - services/thing-data-uploader/ 폐기·삭제 (P2)
    - thing_logger package.xml에 python3-requests exec_depend 추가 (uploader 전용)
    명세 V7.1 조항 수정·web/README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
2026-08-05 S15P11C103-125 docs: landmark·digest 합의문서에 검증 결과 반영
    - D3(스키마 확정)는 D1·D2와 분리 적용 가능함을 명시 — 131 시점에
    켜도 업로드 종단은 D1·D2만으로 동작
    - EC2 후속 수정 2건 추가: make_session.sample_payload()의 dict 형식이
    SCHEMA_DECIDED=True에서 자기 검증에 걸림, 가드 테스트(assertFalse)
    갱신 필요
    - 명세 잔재 규모 기록: V7.md "세 파일" 43곳, multipart 합계 80.25MiB는
    3파일 합(landmark 상한 누락 P-3)
    - 리스크 추가: Jira 125 완료조건의 수동 CLI 줄이 D4와 모순(문구 수정 보류)
2026-08-05 S15P11C103-91 docs: service_unavailable 예시를 노드 배치에 맞게 정정
    기록 서비스 3종(start/stop_recording, set_mimic_result)은 Raspberry Pi가
    아니라 Jetson의 logger가 제공한다(S15P11C103-125 배치 확정). Pi 중심
    예시가 통합 시험에서 엉뚱한 장비를 확인하게 만들 수 있어 제어/기록의
    제공 위치를 구분해 적는다.
2026-08-05 S15P11C103-125 docs: EC2 수정요청 반영확인 기록 및 통합시험 절차 추가
    - EC2 수정요청 문서: 김기현 96 브랜치에 INCLUDE_IN_DIGEST=True 반영 확인,
    로봇 exporter 실제 metadata로 양쪽 digest 바이트 단위 일치 교차검증(§7),
    잔여 항목(REQUIRED 엄격화·D3·P-3·develop 머지) 기록
    - 통합시험 절차 문서(138 준비): 시험 전 준비물, 단계별 시험 순서(단독 기동
    →해피패스→멱등·충돌→장애 주입→대용량 landmark 실측), 예상 오류→원인
    지도, 통과 기준
2026-08-05 S15P11C103-125 style: uploader docstring pep257(D213·D403·D207) 준수
    colcon test 게이트(test_pep257) 통과를 위한 docstring 형식 수정.
    로직 변경 없음.
2026-08-05 S15P11C103-147 feat: Jetson vision launch에 thing_logger logger 노드 추가
    2026-08-05 팀 결정(docs/decisions/2026-08-05-logger-uploader-jetson-배치.md)에 따라
    vision.launch.py 기동 노드를 6개로 확장(FR-42). 격리 uploader는 ROS 노드가
    아니므로 launch에서 제외(별도 프로세스/컨테이너).
2026-08-06 fix(control): validate mimic rate in command guard [S15P11C103-100]
    [control.yaml]
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2026-08-06 [S15P11C103-67] 7축 DYNAMIXEL 모터 드라이버 및 엄지 제어 통합
    [motor_status.yaml, motors.yaml, motors_fingers_only.yaml]
2026-08-06 S15P11C103-153 feat: web_bridge·logger 전용 launch 추가
    vision.launch.py 하나가 Jetson 몫 전부를 띄우는 구조라 통합 시험에서
    브리지·기록만 따로 기동할 수 없었다. 역할별 launch를 신설한다.
    - web_bridge.launch.py: mjpeg_streamer + web_bridge_node. 파라미터는
    기존 vision.yaml의 두 절을 재사용한다(노드 이름 키가 달라 충돌 없음).
    - logger.launch.py: thing_logger logger 노드. 격리 uploader 데몬은 ROS
    노드가 아니므로 이 launch가 시작하지 않는다.
    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
2026-08-06 fix(hardware): latch thumb transition timeout [S15P11C103-148]
    [motor_driver_node.cpp]
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2026-08-06 fix(integration): update MIMIC speed and startup stability [S15P11C103-132]
    [vision.yaml]
2026-08-06 [S15P11C103-149] SAFE 자세 복귀 및 엄지 제어 안정화
    [motors.yaml, motors_fingers_only.yaml]
2026-08-06 feat(hardware): configure Dynamixel buses for 1 Mbps [S15P11C103-154]
    [motor_status.yaml, motors.yaml, motors_fingers_only.yaml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]
2026-08-06 fix(control): update control configuration [S15P11C103-101]
    [control.yaml]
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2026-08-06 S15P11C103-131 fix: 세션 시작 이전 선두 레코드를 export에서 제외
    기록 시작 직전에 생성된 프레임·모터 상태가 파이프라인 지연으로 기록 시작
    이후에 도착하면 stamp가 세션 시작보다 이전이 되어, 통합 시험에서 정상 세션의
    export가 전부 실패했다.
    - _PreSessionRecordError를 추가해 세션 이전 stamp를 별도로 식별한다.
    ExportValidationError의 하위 타입이라 skip 처리를 빠뜨려도 기존과 같이
    안전하게 실패한다.
    - 파일의 선두 레코드에서만 건너뛰고 제외 건수를 경고 로그로 남긴다. 정상 행이
    나온 뒤 다시 나타나면 시계 이상이므로 기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
    [exporter.py]
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2026-08-06 fix(web): stabilize hand-loss camera layout [S15P11C103-138]
2026-08-07 fix(teleop): decouple ROS executor from curses UI [S15P11C103-155]
    [keyboard_teleop_node.py]
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2026-08-07 fix(web): mirror camera preview [S15P11C103-138]
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2026-08-08 fix(control): update sequence configuration [S15P11C103-101]
    [control.yaml]
2026-08-09 [Merge] develop 최신 개발 내용 main 반영
    [BOM.csv, Thing_V3.blend, Thing_V3_01_01_V3_PRINT_01_PALM_CORE.stl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]
2026-08-10 fix(web): improve camera and communication status display [S15P11C103-113]
2026-08-10 feat: sync final SSAFY project snapshot
    Import S15P11C103 main at 3062eda and retain the GitHub portfolio README format.
    [motor_status.yaml, motors.yaml, motors_fingers_only.yaml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]
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2026-09-17 Readme 수정
